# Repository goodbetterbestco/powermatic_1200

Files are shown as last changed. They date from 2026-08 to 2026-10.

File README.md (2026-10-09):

# Powermatic 1200 Controls Retrofit

Rev P is the current contactor-based design for the Powermatic 1200. Retain the existing motor, OFF/LOW/HIGH drum switch and fixed FWD/REV/STOP button station. Operator controls use 24 VDC; motor-power switching is located in the panel enclosure.

## Active files

- [Rev P BOM](Powermatic_BOM_revP.csv) — current component list, grouped by unique part number.
- [Wire-size policy](WIRING_STANDARD.md) — conductor gauges, motor/controls conduit plan, component exceptions and documentation responsibilities.
- [KiCad project](kicad/powermatic_1200/powermatic_1200.kicad_pro)
- [Schematic](kicad/powermatic_1200/powermatic_1200.kicad_sch) — work in progress.
- [Open work](TODO.md)

The contactor references are KF (forward), KR (reverse), KL (low speed), KH (high-speed supply) and KS (high-speed shorting). The current design also includes the selected disconnect, fuses, supply-input breaker, motor overloads, coil suppression, coil-enable relay, white indicator and M12 E-stop connection. The BOM records selected parts; schematic completion and commissioning remain open.

## Review the BOM

Use the local [BOM review editor](https://github.com/goodbetterbestco/bom_review)
to edit the CSV in a browser:

Double-click **Open BOM Review.app** in Finder. It opens the first CSV whose
filename contains `bom` (case-insensitive, alphabetically sorted) beside the
launcher. The launcher can be copied into another project folder to review its
BOM. Repeated launches reuse the same reviewer server. It runs in the background;
the launcher opens a Terminal window only when none exists and leaves existing
Terminal sessions alone. Closing Terminal does not stop the reviewer.

Or launch from a terminal:

```sh
python3 ~/Projects/bom_review/review.py ~/Projects/_hardware/powermatic_1200/Powermatic_BOM_revP.csv
```

The editor uses TYPE, NAME, QUA, PACK, UNIT, COST, LINE, SUPPLIER and SPN.
LINE calculates QUA × COST; the header total includes all parts. Blank and summary
rows are omitted. Other cells remain editable text. **Overwrite** saves directly
to the original project CSV. **Save CSV** downloads a separate copy. Relaunch the
Finder app after updating the reviewer to use its latest server features.

## Generate a wiring review

The [wire-size policy](WIRING_STANDARD.md) defines conductor classes and exceptions.
`Open BOM Review.app` and `Open Wire Schedule Review.app` use the shared
`bom_review` editor. On launch they extract fresh saved KiCad data into the
existing BOM or wiring CSV. The browser's Refresh button repeats extraction.
Overwrite saves browser edits only to that live CSV; it never writes to KiCad.
There is one CSV per schedule and no automatically retained CSV history.

The BOM's SOURCE column distinguishes KiCad-linked rows from Local purchasing
items. SOURCE KEY, hidden in the grid, identifies linked parts across refreshes.
KICAD QTY is the modeled count; purchasing QUA and packaging remain CSV data.
Refresh retains all Local rows and the purchasing fields on linked rows. Initial
tagging preserves all existing BOM values. See [schedule extraction](tools/schedules/README.md).

Both wire-review Finder apps use the same live `Wire_schedule.csv`. Complete
saved PCB trace paths become physical wire rows; bends/arcs/vias do not create
extra wires. Refresh updates routes and footprint termination data and reports
unrouted or ambiguous connections. There are currently no saved traces, so a
fresh schedule contains zero routed wires. Old `Wire.Wxxx` fields are not used.

See [KiCad-owned wiring](tools/wiring/README.md) for the record editor, routing
rules and generated coverage report. To generate without opening a browser:

```sh
python3 tools/wiring/generate.py
```

## Shared parts library

Control-net names follow the shared `_parts` naming convention. See the
[project signal table](SIGNAL_NAMING.md) for operator connections, enable paths,
coil feeds and intermediate links.

Reusable assets are kept in the separate `_parts` repository:

- `symbols/Controls.kicad_sym` — control symbols.
- `datasheets/` — product documents and drawings, including the May 1968 Bulletin 365 catalog.
- `3dmodels/Controls/` — 21 vendor STEP files and three user rail/duct STEP files, in their original orientations.
- `reviews/Controls_Panel_Models_2026-09-25/` — source mapping and verified file hashes.

Controls layout footprints have not been created. Model orientation, mounting datums and terminal positions still require review before footprint use. External L15-20 plug, drum-switch and button-station modeling is deferred. The fuse model is excluded; its holder and cover models are available.

Component placement will determine the enclosure size. The 350 mm DIN rail is the current working model; duct cut lengths and rail count remain to be determined.

## Archived working material

The mechanical collection, generated reports, previous BOM snapshot and earlier project notes are preserved in [archive commit 8ceac95](https://github.com/goodbetterbestco/powermatic_1200/tree/8ceac956c50b004d06b5bfea7e3169a44bf2d5c7). They were removed from the active tree after the archive was pushed and the shared-library asset copies were verified. Older Rev M design files remain in earlier Git history.

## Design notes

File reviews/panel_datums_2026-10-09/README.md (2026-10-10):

# Panel datums and integer wiring-target coordinates

Owner-authorized saved/paused checkpoint, 2026-10-09. Updated J2/J4/J5 glands,
SW1 disconnect, H1/H2 indicators and J1 M12 panel socket. Eight shared library
files include the underlying BNSPDX-23-W gland and its installed mains-plug proxy.

The glands use Y=0 at the outer wall and X=0 at the gland axis. SW1 uses X=0 at
the outer wall and Y=0 at the shaft axis. The lamps move the datum from the old
X=-16.82571 mm bezel underside to X=0. The M12 socket moves its modeled
sealing-ring rear tangent from old X=3 mm to X=0. This is the nominal modeled
seal plane; the STEP represents the uncompressed seal, not installed gasket
compression. The local TE drawing distinguishes the front shoulder, seal and
rear locking nut. The local Schneider drawing places the panel at the bezel
underside, 11 mm behind the operating face.

All 54 library pad centers, including the 46 targets in the seven installed
instances, are nearest-integer X/Y after the datum change; the largest rounding
adjustment on one axis is 0.45 mm. Native KiCad pad coordinates were checked
at an integral origin and at 0/90/180/270 degrees. These are panel-layout wiring
targets; rounding does not alter hardware outlines or manufacture dimensions.

Placed origins compensate the new local datums so the physical X/Y location,
orientation, model X/Y, drawing details and instance text remain fixed. Pad
numbers, nets, sizes, drills and UUIDs are retained. All 89 other instances and
all board text outside the seven edited footprint blocks remain byte-identical.
The current board has 277 pads and zero track segments, retained by the update.

H2 model Z was 0 mm while H1 model Z was 60.05 mm. H2 now uses 60.05 mm as well;
the lamp source's operating axis is 14.95 mm above its transformed model origin,
so both axes are 75 mm above KiCad's component plane, matching the SW1/J1
mounting-axis height. The two lamp library defaults also use 60.05 mm. H1's
placed height and all device wall positions remain fixed.

The five relevant schematic instances already select the same updated library
IDs. J4/J5 are PCB-only mechanical glands. The schematic is retained verbatim;
no symbol-body, wiring or footprint-ID migration is needed for this in-place
library update. Native netlist and ERC comparison checks the saved consuming
schematic. Baseline ERC: zero errors, one H1 library-symbol-mismatch warning.
The baseline DRC CLI aborted with exit 134 before producing a report.

`manifest.json` records exact origins, source/candidate hashes and every rounded
pad. `prepare.py` records the transformation. `layout.svg`/`layout.png` are
native exported isolated-footprint visual evidence: review-only crosses mark
origins; they are not installed device geometry. Appearance was inspected from
this export; no live symbol/editor inspection is claimed.

Applicable shared rules: FP-CTRL-001/005/009/010/011 retain true physical geometry,
full F.Fab detail, existing layer ownership and omitted courtyards. The owner's
explicit closest-integer pad instruction supersedes exact fan-out spacing in
FP-CTRL-002/003 for these wiring targets. FP-CTRL-006/007/008 preserve the existing
reference-only labels and their placed appearance. No electrical symbol geometry
was changed, and this is not a claim of full library-review completion.

Final saved-project checks: native library/board load and serialization/reload pass; all 63 net memberships are unchanged; ERC has zero errors and the unchanged one H1 library warning. Final DRC also aborts with exit 134 and produces no report. No DRC pass is claimed. `before.zip` in the consuming project review restores both project and library source checkpoint files.

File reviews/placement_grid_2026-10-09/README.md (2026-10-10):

# Integer panel placement and 462 mm backplate

Owner-authorized layout update, 2026-10-09. This PCB is an industrial-controls
alignment and routing view. Whole-millimetre datums take priority for ease of use.
The policy is recorded in the project's WIRING_STANDARD.md.

The backplate outline is 462 x 462 mm, from (0,0) to (462,462). Its existing
notches and mounting holes retain their local shapes, radii and distances from
the nearest edges. Upper corner groups move upward by 0.482 mm; right corner
groups move right by 0.482 mm. Long spans grow accordingly. The native outline
remains closed.

The enclosure remains 508 x 508 mm. Controls:EN4SD20208GY_Open_Front_Grid1mm
centers it on the 462 mm backplate with a 23 mm border. It retains the original
backplate lower-left footprint origin, placed at PCB (0,462). Enclosure corner
datums are (-23,-23), (485,-23), (485,485), (-23,485). The original library
footprint remains available as the nominal 461.518 mm backplate reference.

The new variant translates enclosure graphics by (+0.241,-0.241) mm and the
model by (+0.241,+0.241,0) mm, accounting for KiCad's opposite model/PCB Y axes.
The source STEP is unchanged and unscaled. Native CAD inspection found nine
solids, including the 508 mm housing, hardware and brackets; the backplate view
comes from the KiCad board. The mapped housing bounds agree with the 2D datums.

Wall-device positions:

| Reference | X mm | Y mm |
|---|---:|---:|
| H1 | -23 | 52 |
| SW1 | -23 | 130 |
| H2 | -23 | 207 |
| J1 | -23 | 308 |
| J2 | 57 | 485 |
| J4 | 385 | 485 |
| J5 | 435 | 485 |

All seven origins and all 46 placed wiring targets are now integer global X/Y.
The pad offsets, numbers, nets, dimensions and UUIDs from the previous datum
update are retained. H1/H2 retain their matching 60.05 mm model Z offsets.
The remaining 88 footprints, including fuse-insert/cover mating assemblies,
retain their saved origins and geometry. There are 96 footprints, 277 pads and
zero track segments before and after. Schematic and project settings are retained.

Native footprint/board load, board serialization/reload, whole-mm origin/pad
checks, backplate outline continuity and hole-radius checks pass. The focused
native SVG/PNG shows the frame and the seven wall devices; its extra viewport
outline is review-only. Appearance was inspected from that export.

Applicable checklist: FP-CTRL-001 preserves the hardware model geometry while
adapting the authorized routing view; FP-CTRL-009 retains layer ownership;
FP-CTRL-011 retains the enclosure/device physical projections without adding
courtyards. No electrical symbol body changes or live Symbol Editor review are
claimed. This is not a PCB fabrication footprint/layout review.

`manifest.json` records exact placement and model bounds, `prepare.py` records
the transforms, and `before.zip` restores the pre-update project files.

Final saved-project ERC reports zero violations. The DRC CLI aborts with exit 134 before writing a report, as in prior checks; no DRC pass is claimed. Final native checks and source-preservation results are recorded in validation.json.

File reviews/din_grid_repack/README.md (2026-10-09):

# DIN layout and pin-coordinate audit

The final layout uses 12 shared `_Grid1mm` variants on 71 eligible DIN footprint instances.
All 205 pin pads in those instances and both mounting faces are on exact integer coordinates.
The two rows are packed as assemblies on Y=130 mm and Y=308 mm; their grid-body envelopes
fit the existing 400 mm rails without overlap between independent assemblies.

The original nominal footprints, STEP models and F.Fab detail are retained as hardware
references. The grid variants implement the owner-requested routing representation.
Pin coordinates use upward ceiling rounding. Halfway mounting walls use the outward
integer. Fuse inserts/covers retain mating offsets, and non-DIN components were unchanged.

The final saved PCB contains 96 footprints and 277 numbered pin pads. 86 footprint origins have integer X and Y; ten remain fractional: six fuse/cover mating datums and four wall connectors.
The coordinate workbook includes every pin pad and every footprint origin. The 36
padless footprints are listed on the Origins worksheet; no pin coordinates were invented.

## Grid classification

Coordinates are absolute KiCad board millimetres: X increases right, Y increases down.
The saved grid origin is (0,462) mm. Both axes must match exactly; no numerical tolerance
is applied. Metric candidates are 5, 2.5, 2, 1, 0.5, 0.25, 0.2, 0.125, 0.1, 0.0625,
0.05, 0.025 and 0.01 mm. Inch candidates are 100, 50, 25, 10, 5 and 1 mil.
`None of tested grids` means no match in this finite set; a finer or shifted lattice
may still describe the point. Local footprint coordinates and local grid matches are
also included, so nominal terminal geometry can be distinguished from placement offsets.

## Files

- [Final layout and validation](grid1mm/README.md)
- [Final exported layout](grid1mm/layout.png)
- [Sortable coordinate workbook](../../outputs/01a11f24-8bcc-77e0-af58-1f3d5466a457/pin_coordinates.xlsx)
- [Complete coordinate JSON](coordinates.json)
- [Original source recovery snapshot](before_board.zip)
- [Before-grid PCB and schematic snapshot](grid1mm/before_grid.zip)

## Final grid counts

| Classification | Pins |
|---|---:|
| Metric | 205 |
| None of tested grids | 72 |

## Remaining fractional footprint origins

| Reference | Part | X (mm) | Y (mm) | Reason |
|---|---|---:|---:|---|
| F1 | FRN-R-10 | 84.484112 | 130.000000 | Assembly mating datum |
| F2 | FRN-R-10 | 109.484112 | 130.000000 | Assembly mating datum |
| F3 | FRN-R-10 | 134.484112 | 130.000000 | Assembly mating datum |
| J1 | T4171310004-001 | -25.000000 | 307.500000 | Outside DIN repacking scope |
| J2 | 3PH-4W-PLUG | 57.000000 | 485.241000 | Outside DIN repacking scope |
| J4 | BSPDX-23-W | 385.000000 | 485.241000 | Outside DIN repacking scope |
| J5 | BSPBX-22-W | 435.000000 | 485.241000 | Outside DIN repacking scope |
| REF** | CVR-RH-25030 | 84.500000 | 130.000000 | Assembly mating datum |
| REF** | CVR-RH-25030 | 109.500000 | 130.000000 | Assembly mating datum |
| REF** | CVR-RH-25030 | 134.500000 | 130.000000 | Assembly mating datum |

Source SHA-256: `fbe823d4e8d51115c49e3e389eada75a6284db6dfc230625cb2b023f1e0f2385`.

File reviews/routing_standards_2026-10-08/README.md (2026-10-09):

# Routing standards — 2026-10-08

The saved project now has six AWG width profiles and functional netclasses for
incoming mains, panel power, motor power, control, direction, speed and PE.
A separate DEVICE_INTERNAL class marks retained straps and direct-mounted
connections without assigning a conductor gauge. See
[WIRING_STANDARD.md](../../WIRING_STANDARD.md#kicad-route-widths-and-netclasses)
for the policy and routing instructions.

KiCad 10.0.7 natively resolved all 53 named nets: 43 have an AWG default and
10 fixed connections retain the Default drawing width. Thirteen nets have
different gauges on different physical wires; select the appropriate AWG preset
for those individual conductors. The six available presets are 0.643, 1.024,
1.290, 1.628, 2.052 and 2.588 mm.

The PCB Editor preference is 90 degree rounded, with free-angle mode disabled.
The project local settings disable width pickup from existing tracks and enable
netclass grouping in Net Inspector. These are saved preferences for the next
editor launch. The corner mode remains selectable through KiCad shortcuts.

Validation: native project loading and netclass resolution passed. Both the
96-footprint PCB and the schematic remain byte-for-byte identical to the
user-saved baseline. The 18 existing 0.2 mm track segments were preserved.
The project diff is limited to netclasses, assignment patterns and width presets;
existing user changes were retained.

The full assignment table, mixed-gauge declarations, native effective widths,
source hashes and preference-backup path are in [assignments.json](assignments.json).

| Net | Functional group | Default AWG | Default width (mm) | Declared AWGs |
|---|---|---:|---:|---|
| `+24V` | `CONTROL` | 18 | 1.024 | 18, 22 |
| `+24V_EN` | `CONTROL` | 18 | 1.024 | 18 |
| `/CONTROL_ESTOP_CONTACT_LINK` | `CONTROL` | 22 | 0.643 | 22 |
| `/CONTROL_K3_CONTACT_LINK` | `CONTROL` | 18 | 1.024 | 18 |
| `/DIRECTION_FWD_COIL` | `DIRECTION` | 18 | 1.024 | 18 |
| `/DIRECTION_REV_COIL` | `DIRECTION` | 18 | 1.024 | 18 |
| `/HS_SHORT` | `PANEL_POWER` | 14 | 1.628 | 14 |
| `/L1_FUSED` | `PANEL_POWER` | 14 | 1.628 | 14 |
| `/L1_HIGH` | `MOTOR_POWER` | — | — | fixed |
| `/L1_LOW` | `MOTOR_POWER` | — | — | fixed |
| `/L1_PSU` | `PANEL_POWER` | 14 | 1.628 | 14 |
| `/L2_FUSED` | `PANEL_POWER` | 14 | 1.628 | 14 |
| `/L2_HIGH` | `MOTOR_POWER` | — | — | fixed |
| `/L2_LOW` | `MOTOR_POWER` | — | — | fixed |
| `/L2_PSU` | `PANEL_POWER` | 14 | 1.628 | 14 |
| `/L3_FUSED` | `PANEL_POWER` | 14 | 1.628 | 14 |
| `/L3_HIGH` | `MOTOR_POWER` | — | — | fixed |
| `/L3_LOW` | `MOTOR_POWER` | — | — | fixed |
| `/SPEED_HIGH_SHORTING_COIL` | `SPEED` | 18 | 1.024 | 18 |
| `/SPEED_LOW_COIL` | `SPEED` | 18 | 1.024 | 18 |
| `0V` | `CONTROL` | 18 | 1.024 | 18 |
| `CONTROL_ESTOP_DISABLED_FB` | `CONTROL` | 18 | 1.024 | 18 |
| `CONTROL_ESTOP_ENABLE` | `CONTROL` | 18 | 1.024 | 18, 22 |
| `CONTROL_LOW_OVERLOAD_ENABLE` | `CONTROL` | 18 | 1.024 | 18 |
| `CONTROL_OVERLOAD_ENABLE` | `CONTROL` | 18 | 1.024 | 16, 18 |
| `CONTROL_RUN_ENABLE` | `CONTROL` | 18 | 1.024 | 16, 18 |
| `DIRECTION_ENABLE` | `DIRECTION` | 18 | 1.024 | 16, 18 |
| `DIRECTION_FWD_CMD` | `DIRECTION` | 18 | 1.024 | 16, 18 |
| `DIRECTION_REV_CMD` | `DIRECTION` | 18 | 1.024 | 16, 18 |
| `L1_DIR` | `PANEL_POWER` | 14 | 1.628 | 14 |
| `L1_IN` | `INCOMING_MAINS` | 12 | 2.052 | 12, 14 |
| `L1_SW` | `PANEL_POWER` | 14 | 1.628 | 14 |
| `L2_DIR` | `PANEL_POWER` | 14 | 1.628 | 14 |
| `L2_IN` | `INCOMING_MAINS` | 12 | 2.052 | 12, 14 |
| `L2_SW` | `PANEL_POWER` | 14 | 1.628 | 14 |
| `L3_DIR` | `PANEL_POWER` | 14 | 1.628 | 14 |
| `L3_IN` | `INCOMING_MAINS` | 12 | 2.052 | 12, 14 |
| `L3_SW` | `PANEL_POWER` | 14 | 1.628 | 14 |
| `M1_T1` | `MOTOR_POWER` | 14 | 1.628 | 14 |
| `M1_T2` | `MOTOR_POWER` | 14 | 1.628 | 14 |
| `M1_T3` | `MOTOR_POWER` | 14 | 1.628 | 14 |
| `M1_T4` | `MOTOR_POWER` | 14 | 1.628 | 14 |
| `M1_T5` | `MOTOR_POWER` | 14 | 1.628 | 14 |
| `M1_T6` | `MOTOR_POWER` | 14 | 1.628 | 14 |
| `Net-(S3-HI3_B)` | `SPEED` | — | — | fixed |
| `Net-(S3-HI5_T)` | `SPEED` | — | — | fixed |
| `Net-(S3-HI6_T)` | `SPEED` | — | — | fixed |
| `Net-(S3-HI8_B)` | `SPEED` | — | — | fixed |
| `PE` | `PE` | 14 | 1.628 | 12, 14 |
| `SPEED_HIGH_CMD` | `SPEED` | 18 | 1.024 | 16, 18 |
| `SPEED_HIGH_COIL` | `SPEED` | 18 | 1.024 | 18 |
| `SPEED_LOW_CMD` | `SPEED` | 18 | 1.024 | 16, 18 |
| `SPEED_LOW_K6_NC_LINK` | `SPEED` | 18 | 1.024 | 18 |

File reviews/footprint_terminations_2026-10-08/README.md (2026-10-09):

# Footprint-owned terminations

The owner requires TERM 1 and TERM 2 to belong to their endpoint parts. The
saved PCB now holds 305 hidden F.Fab `Termination.<terminal>` fields on 67
footprints. Edit these selections in Footprint Properties. They are project
instance data, so preserve them when updating footprints from their libraries.
Reports are derived outputs.

The migration moves all 182 existing symbol termination fields into their
corresponding footprints and removes the symbol copies. It also removes
`term1`/`term2` from the three surviving schematic wire records. The generator
reads TERM 1 from the source footprint and TERM 2 from the destination footprint.
Missing footprint fields stop export instead of using a wire-record fallback.
The record editor no longer accepts termination-copy arguments.

All 33 feedthrough/ground blocks' 66 wire clamps now describe the part capability:
`Ferrule or twin ferrule as required`. One conductor uses a ferrule; two in one
clamp use a twin ferrule. The owner clarified that blocks and unused jumpers
are available graphics until needed during routing. Part fields therefore carry
no wire-gauge or barrel-length assignment, and unallocated clamps are not
reported as missing termination choices. Actual conductor gauges remain in wire
records/sizing declarations. Ferrule size, length and single/twin form are chosen
when routing assigns conductors. Every block records `Wire.TerminationPolicy`;
grounding-block PE rail feet retain their conductive-contact classification.
`ferrule_policy.json` records the initial family requirement and
`block_capabilities.json` records the owner's allocation clarification and
geometry-preservation check. Other parts' existing barrel-length and
ring-dimension TBDs are retained.

Gland route markers are classified as cable pass-throughs without electrical
terminations. Mechanical interlock markers and grounding-terminal rail contacts
are also classified explicitly. Legacy enclosure, door and backplate stud
descriptions live on the enclosure footprint; rail lug descriptions live on the
two rail footprints. Those legacy bond selections remain pending reconciliation
with the newer bonding plan and do not establish additional wire connections.

At the owner's request M1, J2, S1 and J6 now have metadata-only footprints.
Their terminal inventory is stored in `Wire.TerminalPins`, with one termination
field per terminal. They have no pads, artwork or models, are marked board-only,
allow missing courtyards, and are excluded from BOM and position exports. Their
hidden fields on F.Fab do not change the panel drawing. Their schematic symbols
and electrical connections are retained.

H1 and H2 still have older symbol UUIDs in the board paths. Before associating
their termination fields, the migration verified unique references, matching
MPNs, complete matching terminal inventories and identical native net names.
It preserves the existing paths, placements and models. Both receive the
existing blue 18 AWG indicator ferrule selection.

Validation performed:

- Native KiCad PCB loading: 97 footprints, 305 hidden termination fields.
- Four metadata-only owners: zero pads, graphic items or models and the intended
  board-only/BOM/position exclusion attributes.
- Structured comparison: every original footprint's geometry, placement, pads,
  nets, models, UUIDs and non-termination fields unchanged. All other PCB objects
  unchanged. Schematic changes restricted to removal of termination copies.
- Native schematic netlist comparison: all 186 pin-to-net assignments identical.
- Migration repeated on its result: byte-for-byte idempotent.
- 33 wiring tests passed, including conflicting owner selections, migration,
  external owners, footprint edits flowing into schedule output and missing
  fields rejecting stale wire-record fallbacks.
- Source hashes checked before installing both saved files after the owner's
  saved/editing-paused confirmation. Whitespace check passed.

`validation.json` records hashes and preservation checks. `provenance.json`
records the origin of every migrated selection. These are evidence, not runtime
data sources. Run `python3 tools/wiring/terminations.py` to review the saved PCB.

The rest of the physical wire-record migration remains unchanged. Complete
schedule generation still fails on deleted schematic endpoint UUIDs. No wire
allocation, routing, cut-length redesign, DRC severity changes or library edits
were included in this task.

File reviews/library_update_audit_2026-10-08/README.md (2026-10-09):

# Schematic library-update audit — 2026-10-08

The saved schematic has ten library-symbol-mismatch warnings and no ERC errors.
All ten instance caches were compared with the current Controls definitions selected
by their non-LCSC catalog records. The pin sets, names, electrical types, full pin
definitions (including coordinates, lengths and text styles), body geometry and
root electrical/placement attributes agree.

| References | Part | Pins per symbol | Electrical/drawing differences |
|---|---|---:|---|
| SP1, SP2, SP4, SP5, SP6 | HMX1-SSVRC-DC | 2 | None |
| FH1 | RM25030-3SR | 6 | None |
| SW1 | 222102 | 6 | None |
| K3 | HC3096N-52-900-24 | 10 | None |
| Q1 | FAZ-D4-2-NA-L | 4 | None |
| PS1 | NDR-240-24 | 7 | None |

The cached copies contain database-added Part ID, Supplier, Supplier PN, inventory
and footprint-filter properties not present in the underlying Controls templates.
K3 also has catalog Package=DIN-RAIL, while its underlying template Package is empty.
These differences do not alter the connection interface. This identifies the source
of the underlying-definition differences, but does not claim every metadata detail
of KiCad's runtime database-generated symbol has been reproduced.

## Update settings

Update only these ten selected instances. Uncheck all Update/Reset Fields selections
and disable Remove fields if not in library, Reset fields if empty in library,
Update/reset field text, visibilities, sizes/styles and positions. Leave Reset alternate
pin to default off. Preserve Wire.*, Termination.*, Mounting, exact MPN, footprint
and the drafted reference/value/Part Name positions.

Run ERC and compare the native netlist after the actual editor update. A temporary
metadata-only cache comparison copy preserved all net memberships, pin functions
and electrical types, but still produced ten warnings. It is not a native editor
update and is not a candidate to install; clearance of the warnings remains to be
verified after the actual library update.

No schematic, PCB or shared-library source files were modified by this audit.
The PCB DRC CLI aborted with exit 134 before producing a report. The owner's
exported PCB-editor DRC report is needed to classify the approximately 300 findings.

This is an electrical-equivalence and structured drawing comparison. No fresh
visual or live Symbol Editor review was performed in this audit; SYM-VIS-001
remains outside this check and no full library-review completion is claimed.

[KiCad update-symbol documentation](https://docs.kicad.org/10.0/en/eeschema/eeschema.html#updating-and-exchanging-symbols)

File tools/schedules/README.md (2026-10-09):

# Live schedule extraction

`kicad_schedules.json` connects the shared `bom_review` Finder launcher and Refresh
server to this project's `extract.py`. Each mode has exactly one live CSV:
`Powermatic_BOM_revP.csv` and `Wire_schedule.csv`. Successful extraction overwrites
that file. Failure preserves it. No CSV versions or backup files are retained.
Make any desired copies elsewhere yourself.

The browser/editor, source-tag preservation, generic BOM row merge and refresh
transaction live in `/Users/evanthayer/Projects/bom_review`. This adapter reads
the saved schematic and PCB and applies Powermatic's component/wire rules.

## BOM ownership

- SOURCE=KiCad: linked to a stable SOURCE KEY and refreshed from modeled parts.
- SOURCE=Local: purchasing-only data remains in this CSV and survives refresh.
- KICAD QTY: modeled piece count, independent of purchasing QUA and packaging.

Initial tagging only adds these columns; it preserves every existing nine-column
cell. Matches use unique saved MPN/supplier identifiers, whole identifier tokens
in vendor-prefixed SKUs or unique part names. Ambiguous rows stay Local.

Refresh updates a linked part's name where KiCad provides one and its modeled
count. Local purchasing quantity, price, packaging, supplier and supplier SKU
are retained. Explicit `BOM.PACK`, `BOM.UNIT`, or `BOM.COST` KiCad fields can
supply those purchasing fields when present. Newly specified native parts are
added with purchasing quantity left for the user. Deleted linked parts are
removed; Local entries are kept.

This is a panel BOM. Existing purchasing rows can link to mechanical Controls
models even when those models are excluded from a conventional PCB BOM. Their
modeled quantities include available graphics and are informational until
physical allocation. Such excluded models do not create new purchasing rows.
Metadata-only footprints are not counted again; schematic units and placed
footprints representing the same component are counted once. Assemblies without
an actual part identifier are not automatically added as new purchasing SKUs.

## Wiring ownership

The saved PCB traces are the physical wire source. A continuous pad-to-pad
path produces one wire row. Connected segments, bends, arcs and via layer changes
remain within that wire. A terminal met along the path splits it into separate
wires. Branches away from a terminal/splice footprint are rejected as ambiguous;
unfinished paths are omitted and reported. Cable-gland IN/OUT routing markers
continue the same wire, using their saved jumper groups, rather than becoming
extra wire ends. Unused block graphics produce no wires.

Endpoint nets are checked against the saved schematic. Board-only unassigned
clamps acquire the circuit from their actual traced connections for export;
different nets on internally common clamps are rejected. The exporter does not
write back to KiCad or assign pad nets in the source file.

AWG comes from footprint `Wire.AWG.<pin>` overrides, schematic `Wire.Sizes`, or an
existing gauge-bearing termination selection. Missing/conflicting sizes stay
blank with a warning; copper trace width is not interpreted as a wire gauge.
Terminations come from footprints. Generic block fields resolve to single or
twin ferrules based on the number of completed routed wires sharing that clamp.

LENGTH is a cut estimate: native route length plus 100 mm, rounded upward to
10 mm. Native arcs use curved length.
Vias are drawing-layer transitions and add no physical via/PCB-thickness length.

Stale sizing metadata produces warnings and cannot supply an outdated gauge.
Conflicting nets on internally common block clamps are reported without hiding
the recorded routes. These wires have `net-conflict` review state in the
extraction report, and the overall routing review remains incomplete.

Old schematic `Wire.Wxxx` records are no longer a route source and do not block
trace export. There are currently no saved traces, so fresh wiring extraction
produces the eight-column header with zero routed wires and reports incomplete
electrical coverage. Only a saved completed trace path adds a wire; drawing in
an unsaved editor does not change extraction.

## Data direction

Saved KiCad data flows into the schedules. CSV-owned purchasing entries/fields
stay local. Browser Overwrite saves only the current CSV, including source tags.
There is no path from a browser edit back into the schematic, PCB or libraries.

Tests cover source changes, package quantity preservation, Local row retention,
removed linked parts, duplicate/missing keys, ambiguous matching, CSV tag round
trips, refresh failures and concurrent saves.

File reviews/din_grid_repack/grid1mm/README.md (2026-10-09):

# Grid-aligned DIN layout

Installed 12 shared `_Grid1mm` elevation variants on 71 placed footprint instances.
All 205 pin pads in those instances lie on exact integer X/Y coordinates.
Their left and right mounting faces are also integer X. The 77 DIN-associated
instances were restacked as assemblies on the existing 130 mm and 308 mm rail
centre lines, keeping both 400 mm rails. Fuse inserts/covers keep their mating
offsets; their noninteger origins exclude them from the grid-variant operation.

The original footprints and STEP model parameters are preserved. F.Fab remains
the nominal hardware reference; the visible grid view and wire-target markers
are a routing representation. This review verifies 2D grid-envelope packing,
not a change in the manufactured hardware dimensions.

Native checks retain all 96 footprint instances, 277 pin pads, 18 track segments
and the four completed routed endpoint pairs. Schematic footprint overrides
were updated in 16 placed symbols; all 63 nets and 186 pin/net memberships are unchanged.

The exported [layout](layout.png) was visually inspected. Per-instance positions,
route adjustments and identity checks are in [packing.json](packing.json).
The [variant manifest](variants.json) records source hashes and pin rounding.
The preceding saved PCB and schematic are recoverable from [before_grid.zip](before_grid.zip).

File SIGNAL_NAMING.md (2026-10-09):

# Powermatic control signal names

The shared [signal naming standard](../../_parts/SIGNAL_NAMING_STANDARD.md)
governs this project. Use `[FUNCTION]_[DETAIL]_[ROLE]` in uppercase, with the
detail omitted when unnecessary. The active functions are `CONTROL`,
`DIRECTION`, and `SPEED`. Control signals use `CMD`, `ENABLE`, `FB`, `COIL`,
or `LINK` as their role; power rails and motor power conductors retain their
electrical names.

The saved schematic owns net names and connectivity. PCB pad nets, embedded
`Wire.Sizes` declarations, physical wire records and generated outputs must
use that same native name. A leading `/` in KiCad exports denotes sheet scope
and is not part of the functional naming convention. Reusable symbol pin names
and physical terminal numbers remain manufacturer/contact functions.

## Operator connections

| Signal | S2/S3 terminal | Energized meaning |
|---|---|---|
| `CONTROL_OVERLOAD_ENABLE` | S2.5T; retained links to 1T and 3T | Feed has passed the upstream control enable and both overload NC contacts. |
| `CONTROL_RUN_ENABLE` | S2.6T; S3.1B with retained link to 2B | The overload-qualified feed has also passed STOP's NC contact. |
| `DIRECTION_ENABLE` | S2.2B with required link to 4B | Either speed contactor K4 or K6 has closed its auxiliary NO contact, supplying the direction start/holding circuits. |
| `DIRECTION_FWD_CMD` | S2.1B | Forward command path is energized by the button or K1's holding contact. |
| `DIRECTION_REV_CMD` | S2.3B | Reverse command path is energized by the button or K2's holding contact. |
| `SPEED_LOW_CMD` | S3.1T with retained link to 3T | LOW selector command path is energized. |
| `SPEED_HIGH_CMD` | S3.2T | HIGH selector command path is energized. |

S2 retains five external conductors and S3 retains three. This naming update
does not change any connection or establish installation of an unconfirmed link.
The S2 2B-to-4B link remains required and physically unconfirmed.

An energized command net does not prove a button remains pressed or a motor is
moving. `CONTROL_RUN_ENABLE` is a positive permission path, not an active-high
STOP request. Loss of a cumulative enable may result from any upstream open
contact or missing feed; it does not uniquely diagnose the last device.

## Other named control nets

| Signal | Function |
|---|---|
| `CONTROL_ESTOP_ENABLE` | Feed through the E-stop contact chain to K3's coil. |
| `CONTROL_ESTOP_DISABLED_FB` | K3 NC31-32 supplies the red H2 lamp when the E-stop enable relay is released and 24 V power is present. This also indicates an unplugged/broken E-stop loop or a failure to energize K3; it does not uniquely identify the physical button position. |
| `CONTROL_LOW_OVERLOAD_ENABLE` | Intermediate feed after OL4's NC contact and before OL6's NC contact. |
| `DIRECTION_FWD_COIL` | K1 coil feed after the reverse contactor's NC interlock. |
| `DIRECTION_REV_COIL` | K2 coil feed after the forward contactor's NC interlock. |
| `SPEED_LOW_COIL` | K4 coil feed after the high-speed interlocks. |
| `SPEED_HIGH_SHORTING_COIL` | K5 shorting-contactor coil feed after K4's NC interlock. |
| `SPEED_HIGH_COIL` | K6 coil feed after K5's NO sequencing contact. |
| `SPEED_LOW_K6_NC_LINK` | Intermediate low-speed command path between K6's and K5's NC interlock contacts. |
| `CONTROL_ESTOP_CONTACT_LINK` | Intermediate connection between the two E-stop NC contacts. |
| `CONTROL_K3_CONTACT_LINK` | Intermediate connection between K3's series NO contacts. |

`FB` is reserved for an actual feedback contact or sensor. No feedback signal
introduced here indicates shaft motion. A contactor auxiliary contact confirms its defined
contact state, not measured shaft speed or direction. `+24V`, `+24V_EN`, `0V`,
`PE`, phase-stage names and motor terminal names remain power-net identifiers.

## Verification of the naming update

The 2026-10-08 update preserves all net terminal memberships, symbol pin functions
and electrical types. PCB changes are name substitutions only. One schematic
coil label rotates at its original connection point to avoid overlapping a
neighboring symbol. Wires, UUIDs, terminal numbers, component positions and models
are unchanged.
Validate the final native netlist and embedded sizing declarations together.
Review exported operator/control artwork for label readability.

| Shared rule | Result | Evidence |
|---|---|---|
| `SCH-NAME-001` | Pass | All 17 explicitly named control nets use the shared roles. No remaining old-name usages were found in either repository's current searchable files. |
| `SCH-NAME-002` | Pass | Operator/cumulative meanings are recorded above; the native exports were inspected, and the long K5 coil label was rotated without moving its connection point. |
| `SCH-NAME-003` | Pass | Before/after native netlists retain all 64 net groups with identical terminal memberships, pin functions and electrical types. PCB sources retain every non-name byte; schematic sources differ only in names and one label rotation. |

Native PCB loading confirms 90 footprints and 279 pads. The sizing validator
classifies all 172 connected terminals, including eight external S2/S3 wires.
All 27 existing wiring tests pass. Final ERC has zero errors and the same ten
library-symbol-mismatch warnings as the baseline; its violation records are
identical. These checks validate the rename, not fabrication or electrical release.

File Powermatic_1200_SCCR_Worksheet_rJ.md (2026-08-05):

# Powermatic 1200 Retrofit - SCCR Worksheet

**Revision:** J  
**Date:** 2026-08-05  
**Circuit:** nominal 208/240 V, 3-phase VFD input power circuit  
**Status:** **SELECTED POWER-CIRCUIT COMPONENT CHECK PASSED - final panel sign-off requires source verification**

## 1. Design target and source assumption

- Working panel target: **10 kA RMS symmetrical at 240 V maximum**.
- Shop feeder: Siemens three-pole Type QP branch breaker marked **10,000 A RMS symmetrical at 240 V**.
- The breaker's 10 kA interrupting rating is not a calculation or measurement of available fault current.
  Treat `available fault current <= 10 kA` as a provisional design assumption until confirmed from the
  serving transformer and conductor impedance or by a qualified field calculation.
- The finished panel SCCR must be at least the available fault current at the machine connection point.

## 2. Power-circuit path

`shop feeder -> ABB OT30F3 -> LFT300603C / 3 x TJN35 -> Contactor A -> GS23-22P0 VFD`

| Component | Selected device | Published/working SCCR basis | Worksheet result |
|---|---|---|---|
| Branch fuses | 3 x Mersen `TJN35`, Class T, 35 A | Class T current-limiting branch protection; interrupting rating to be retained with the fuse data sheet | Not the limiting component |
| Fuse block | Littelfuse `LFT300603C`, 300 V, 60 A, 3-pole Class T | Listed Class T block; fit one `LFT30060FBC` cover per pole | Not presently identified as limiting |
| Disconnect | ABB `OT30F3`, 30 A, 3-pole, UL 98 | ABB publishes **50 kA** with Class T fuses up to 60 A | Passes 10 kA target |
| Contactor A | Schneider `LC1D18BD`, 18 A AC-3 / 32 A AC-1, 24 VDC | Schneider high-fault table: **100 kA with fuse <=40 A**. Selected fuse is 35 A Class T. | **Passes 10 kA target** |
| VFD | AutomationDirect `GS23-22P0` | GS20 manual specifies 35 A fast-acting Class T `TJN35`; all GS20(X) drives are suitable for circuits up to 100 kA RMS symmetrical | **Passes 10 kA target** |
| Feeder breaker | Siemens Type QP, 3-pole | 10 kA interrupting rating at 240 V; this is not the panel SCCR and not proof of available fault current | Source assumption only |

## 3. Resolution and remaining release items

The former `LC1D09BD` was replaced by `LC1D18BD`. This clears the contactor/fuse mismatch: the selected
35 A Class T fuse is below Schneider's 40 A maximum for the contactor's 100 kA high-fault combination.

Before applying the final panel SCCR marking:

1. Retain the Schneider combination-table page in the panel file and record `LC1D18BD`, 35 A Class T,
   and 100 kA component/combination SCCR.
2. Retain the GS20 manual pages showing `GS23-22P0` with 35 A `TJN35` Class T protection and the
   100 kA short-circuit-withstand statement.
3. Confirm available fault current at the machine by qualified calculation. The branch breaker's 10 kA
   interrupting rating alone does not establish available fault current.
4. Complete the final sign-off fields below and mark the panel at the lowest supported circuit value.

The contactor and VFD no longer present unresolved procurement holds. Do not apply the final panel SCCR label
until the available-fault-current entry and final field sign-off are complete.

## 4. Final sign-off fields

- Available fault current at machine: __________ kA RMS symmetrical at __________ V
- Calculation/source and date: _________________________________________________
- Final Contactor A catalog number: ____________________________________________
- Final fuse catalog/rating: ___________________________________________________
- VFD manufacturer SCCR condition verified: **Yes - GS20(X) manual, 1st Edition Rev E, pp. A-2/A-4 and 2-21**
- Lowest component/combination SCCR: __________ kA
- Final panel SCCR marking: __________ kA RMS symmetrical at __________ V
- Reviewed by / date: __________________________________________________________

## 5. Manufacturer references

- Schneider Electric, *Motor Control Solutions for the North American Market*, TeSys Deca 3-pole
  contactor SCCR table: `LC1D09` maximum 25 A fuse; `LC1D18` maximum 40 A fuse.
  <https://productinfo.se.com/8536db0901_motorcontrolsolutions_db/8536db0901-db-motor-control-solutions/English/8536DB0901R0119%20Motor%20Control%20Solutions%20for%20th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>
- Schneider Electric, LC1D mirror contacts: base-device 21-22 N.C. is the mirror contact.
  <https://www.se.com/uk/en/faqs/FA142116/>
- ABB, `OT30F3` product data and disconnect-switch short-circuit tables.
  <https://empower.abb.com/ecatalog/ec/EN_NA/p/1SCA105068R1001>
- Littelfuse, `LFT300603C` Class T block product data.
  <https://www.littelfuse.com/products/fuses-overcurrent-protection/fuse-holders-fuse-blocks-accessories/fuse-blocks/industrial-fuse-blocks/lft/lft300603c>
- AutomationDirect, *DURApulse GS20 & GS20X Drive User Manual*, 1st Edition Rev E: fuse specification
  table (`GS23-22P0` -> 35 A `TJN35`) and 100 kA short-circuit-withstand statement.
  <https://cdn.automationdirect.com/static/manuals/gs20m/gs20m.pdf>

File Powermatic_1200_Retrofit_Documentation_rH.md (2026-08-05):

# Powermatic 1200 Drill Press — Controls Retrofit

**Machine:** 1967 Powermatic 1200, 3PH tapping/drilling drill press
**Owner / designer:** Evan Thayer — GoodBetterBestCo
**Document rev:** H · **Date:** 2026-07-19
**Design references:** NFPA 79 (Electrical Standard for Industrial Machinery), UL 508A (panel construction)

> **Rev H changes (operator model + logic hardening; prox PNP; pricing).**
> - **Latched bidirectional DRILL run (§3.2, §7).** Reverse now behaves exactly like forward: **one press of REV
>   latches a reverse run** (`C31`) that continues until STOP — symmetric with FWD's `C30`. **Stop-first, opposite-
>   as-stop:** while running one direction, a press of STOP *or* of the opposite button **stops** the run; it takes
>   a **second** press to start the other direction (no plug-reversal under power). The old momentary REV jog on
>   `X005` is removed from normal operation and folded into jog mode below.
> - **JOG MODE (§3.5, §7).** **Hold FWD ≥ 5 s** to enter jog (FWD only). In jog mode **FWD and REV become momentary
>   hold-to-run jogs at 30 Hz** (preset-LOW forced), gated safe/no-fault. **Exit** on a **short (< 5 s) STOP press**,
>   or **60 s idle**, or **any fault**, or **E-stop**. STOP always stops motion first; the < 5 s qualifier only adds
>   the mode-exit. Annunciated as **blinking green = JOG ARMED** (see indicators).
> - **TAP abort hardened (§7 RUNG 13).** A loss of run-permit — which includes an **E-stop / safety trip** (`X011`),
>   drum-OFF, or STOP — now forces the TAP state machine to **IDLE**. Previously `C2`/`C3` survived an E-stop, so a
>   safety reset could **resume a tap with no fresh FWD press**; that auto-restart path is closed. DRILL already
>   self-cleared via `¬C20`; TAP now matches.
> - **DB-resistor over-temp is self-clearing + distinctly annunciated (§4/§7).** Over-temp now drives a dedicated
>   **`C11` (THERMAL)** bit that follows `X012` with a short cool-down delay — it inhibits run and **self-clears**
>   when the resistor cools (no manual reset, and no more fighting the fault-reset rung). Shown as **blinking red**,
>   distinct from a solid-red hard fault, so the operator reads "let it cool" vs "investigate."
> - **Indicators (§4/§7 RUNG 28/29).** Four states on the two machine-front lamps, exactly one active: **green solid**
>   = all-good; **green blink** = jog armed; **red blink** = DB over-temp (self-clearing); **red solid** = safety
>   trip or latched hard fault (top priority). White bus lamp unchanged.
> - **Feed-lever prox NPN → PNP (§4, §12).** Swapped to a **P&F NBN8-12GM50-E2-V1 (PNP-NO)** so it lands on the
>   **standard sinking input common** with every other +24-fed contact. The Rev G split-common (dedicated sourcing
>   group for the NPN unit) is deleted — `X010` stays put, logic sense and fail-safe behavior unchanged.
> - **STO wiring rationale recorded (§6).** STO1/STO2 are fed from the **single** safety output 23-24 by design;
>   **Contactor A (13-14) is the diverse, independent stop channel** and the CWBS12 mirror contact catches a weld
>   via EDM. Redundancy lives in the contactor path, not in STO's own two channels — documented, not changed.
> - **Selector detail (§4).** `X001`/`X002` come from the owner's **XB4BD21** with **both N.O. blocks installed**
>   (supersedes the "ZBE-101" placeholder).
> - **Pricing reconciled (BOM).** DB resistor $55 → **$156** and Contactor A ~$60 → **~$150** were materially low;
>   most other itemized parts verified in-range. See `..._BOM.md`.

> **Rev G changes (procurement + inventory pass; pilot scheme finalized).**
> - **Disconnect re-architected** to a **non-fused rotary switch + separate Class J fuse block** instead of an
>   integrated fusible unit: **Socomec SIRCO M Compact** (UL 98, 3-pole, 60 A, 100 kA SCCR — AD 22013006) feeding a
>   **Mersen US6J3** finger-safe Class J block (3× **JHL35**, Class J 35 A). Operated by an **external S00 rotary
>   handle (Socomec 14741111, NEMA 3R/12)** mounted on a **fixed enclosure wall — not the door** — with **no
>   through-door coupling rod**. Padlockable in OFF; sole disconnecting means.
> - **Contactor A fixed as a WEG CWBS12-33-30C03** IEC **safety contactor** (3-pole, 12 A, 24 VDC coil) with
>   **mechanically-linked mirror contacts integral** (IEC 60947-4-1 / -5-1) — the EDM contact is built in, no add-on aux.
> - **E-stop is now the owner's AvidCNC station** (Schneider mushroom operator + **2× ZB2-BE102 positive-opening N.C.**,
>   M12 4-pin, yellow CM12 enclosure), verified direct-opening and sound — replaces the Eaton E22 assembly.
> - **Feed-lever prox is the owner's P&F NBN8-12GM50-E0-V1** — an **NPN-NO** unit (10–30 V, M12, 8 mm non-flush).
>   Because it's NPN it lands on a **sourcing input common** (see §4); the C2-14D1's two isolated 4-point commons make
>   this clean without disturbing the +24-fed contacts.
> - **24 V control supply is the owner's Mean Well NDR-240-24** (10 A / 240 W). Because it can source ~10 A into a
>   fault, a **24 V bus overcurrent device** is added (§9/§10).
> - **Line reactor deleted** — optional for a single small drive on an ordinary branch; add back only on a stiff
>   supply or if overvoltage nuisance trips appear.
> - **Safety relay pinned to 440R-N23135S** (24 VDC MSR127RP, spring-clamp terminals).
> - **Pilot scheme revised (§4/§6/§7):** two lamps on the **machine front** between the travel limits — **green = "all
>   good," red = "not good"** — driven as **firmware complements** (`Y005`/`Y006`), so exactly one is lit whenever the
>   panel is powered. A **white "power on" lamp (XB4BVB1)** sits at the disconnect, fed straight off the 24 V bus.
>   The old cycle-active / amber "safety-tripped" indications are removed; the safety-relay **41-42 N.C. aux is now spare.**
> - **Wiring detailing (from the wire schedule):** the **PSU primary gets its own 2-pole ~3 A fuse** (the 35 A branch
>   can't protect the 16 AWG PSU tap; both L-N conductors are live at 208 V — 1-pole/120 V only if a neutral is run).
>   The **DB-resistor over-temp thermal switch is wired to spare input `X012`** with a fault rung (§4/§7). A **dedicated
>   PE bond to the machine frame/column** is added (do not rely on the motor mounting bolts), plus DIN-rail and
>   Contactor B frame bonds. All accessories are **home-run** to the panel — no field j-boxes. See `..._Wire_Schedule.md`.

> **Rev F changes (safety parts finalized):** safety relay confirmed as **440R-N23135** (MSR127RP,
> **24 V DC** supply — not the 115/230 VAC N23134/N23133). Output allocation set: 13-14 → Contactor A
> coil, 23-24 → STO, 33-34 → `X011` (fail-safe N.O., no ladder change), 41-42 aux → "SAFETY TRIPPED"
> lamp. Operator devices (DRILL/TAP selector, reset, pilot lamps) now come **from the owner's 22 mm
> stock** — parts to be identified in the shop; E-stop may also be from stock if direct-opening and
> dual-N.C.-capable. *(Rev G supersedes the 41-42 → amber lamp allocation; see above.)*

> **Rev E changes (safety confirmed):** safety relay is an **AB Guardmaster MSR127RP** (monitored
> reset + EDM, ≥3 N.O. outputs → Contactor A coil + VFD STO1 + STO2). E-stop is an **Eaton E22LTA2QB**
> (EN 418, DEMKO, direct-opening) + **E22B1** second N.C. for dual channel + **E22VA8** yellow legend.
> Contactor A confirmed as a **mirror-contact (mechanically-linked) contactor** — required for valid
> EDM. STO wired dual-channel (remove the GS20 STO jumper). Clarified that the IDEC **RF1V** is a
> force-guided relay component, not an MSR127 alternative (optional fan-out / discrete-build only).
> *(Rev G supersedes the Eaton E-stop with the owner's AvidCNC/Schneider station, and names Contactor A
> as the WEG CWBS12 safety contactor.)*

> **Rev D changes (control & logic confirmed):** PLC is a **CLICK PLUS C2-01CPU-2** (no built-in I/O)
> with **two C2-14D1** option modules (16 in / 12 out) — inputs sink/source-selectable, C2-14D1 outputs
> sinking (NPN) so GS20 DIs set to source mode. Interposing relay **CR-B = Murrelektronik 52102** (24 VDC
> coil, DPDT, 6 A/250 VAC); land the Furnas theater coil on its 240 V tap. Added CPU battery (D0-MC-BAT)
> and USB programming cable; CLICK software is a free v3.00+ download.

> **Rev C changes (drive selection + disconnect):** VFD confirmed as **GS23-22P0** against the
> GS20(X) selection tables (CT 7.5 A ≥ 6.42 A FLA); matched accessories named — braking resistor
> **BR-N1-280W50** (50 Ω), branch fuses **3× JHL35 (Class J, 35 A)** per the drive's fuse chart.
> *(Rev G removes the optional line reactor and replaces the integrated fusible disconnect with a
> non-fused SIRCO M + separate US6J3 Class J block.)*

> **Scope of this package.** Complete control retrofit replacing the original all-line-level
> control wiring with a modern low-voltage architecture: safety relay + VFD power section +
> CLICK PLUS logic controller, in a UL 508A–style DIN-rail enclosure. The original drum switch,
> button pendant, and travel limit switches are retained and converted to 24 VDC signaling.
>
> **This is a design package, not a substitute for on-machine verification.** Field-verify every
> mechanical assumption (noted in §12), size branch protection to the *actual* VFD manual, and have
> the finished installation LOTO-validated by a qualified person before production use.

---

## 1. Design intent

The original machine ran every control conductor — drum switch, pendant, limits, contactor
coils — at 208 V line level. That is a large surface area of live wiring for a machine an operator
leans over. This retrofit accomplishes four goals stated at the outset:

1. **Kill the all-line-level hazard.** Everything a human touches (drum, pendant, limits, e-stop,
   selector) *and everything a human reads* (the machine-front pilot lamps) now runs at **24 VDC**.
   The only line-level conductors remaining are inside the enclosure between the disconnect and the motor.
2. **Add single-tap capability.** Reverse-at-bottom, stop-at-top, as a selectable software mode.
   Continuous tapping remains available as a one-rung change (§7, note C).
3. **Keep the original controls and the "chunk."** Drum switch, pendant, and limits are reused as
   24 V inputs. Both original contactors are reused — one doing real safety work, one for sound.
4. **Put the logic in software, not fixed wiring.** A CLICK PLUS PLC brokers every command; the
   sequence lives in ladder, not in relay hardwiring.

### The one rule that governs the whole design
**The PLC is not the safety system.** A standard PLC's outputs can weld and its firmware can hang.
The **E-stop and the over-travel backstop remove motor power through a hardwired safety relay that
does not depend on the controller executing code.** The PLC *sees* the safety state but is never the
thing that makes the machine safe. (This is also why the operator status lamps — which *are* firmware —
are advisory only: see §6/§7.)

### Three layers
| Layer | Trust model | What lives here |
|---|---|---|
| **Safety** | Hardwired, firmware-independent | E-stop → safety relay → drops Contactor A + opens VFD STO |
| **Logic** | CLICK PLUS PLC | DRILL/TAP modes, single-tap state machine, VFD command, preset select, status lamps |
| **Telemetry** *(optional, future)* | Read-only ESP32 | Cycle counting → Cloudflare stack. Never touches control or safety path |

---

## 2. Power topology (see DWG 01)

- Motor is wired **permanently in its 4-pole Δ (high-speed) configuration** — treat it as a plain
  3-lead 1750 RPM motor. The YY (8-pole) leads are capped but left accessible in the peckerhead.
- The **VFD synthesizes both nameplate speed ranges** through the *existing* mechanicals: 60 Hz
  reproduces the high ranges, **30 Hz reproduces the low range exactly** (the drive is doing the
  same 2:1 the pole-change used to do). At 30 Hz the drive holds V/Hz so low-range torque is full.
- The operator still moves the 2-groove belt and spins the Reeves v/s dial exactly as before; only
  "low/high" changes from a winding-swap clunk to a soft VFD preset.

> **Demolition — remove the existing front-of-machine switch.** The machine as found routes line
> from a rear entry j-box, up through an **Allen-Bradley AH7810 3-pole manual switch** on the front
> of the machine, then down to the contactor box. Confirmed on inspection to be a plain 3-pole
> switch (no overload heaters). **Delete it entirely**, along with its front-of-machine cable loop:
> it is line-level wiring in the operator's space — exactly the hazard this retrofit exists to
> remove. Feed the new enclosure **directly from the rear line-entry j-box**; the enclosure's
> disconnect becomes the **sole disconnecting means** (mount its external handle where it is readily
> reachable for LOTO). Before cutting: LOTO and meter to confirm which rear cable is the true
> incoming supply, size the run into the enclosure for VFD input + branch protection, and patch or
> repurpose the vacated front j-box location (candidate spot for the operator pendant/station).

```
208V 3PH 60Hz  ──►  MAIN DISCONNECT — non-fused rotary (Socomec SIRCO M, UL 98, 3-pole 60 A,
                    external S00 handle on a fixed enclosure wall, padlockable OFF, NO door interlock)
                    ──►  BRANCH FUSES (3× JHL35 — Class J, 35 A — in a Mersen US6J3 finger-safe block)
                    ──►  CONTACTOR A (WEG CWBS12 safety contactor, 24 VDC coil, dropped by SAFETY RELAY)
                    ──►  VFD (GS23-22P0, 2 HP / 230 V class / 3PH input)  +DB resistor, STO
                    ──►  MOTOR (permanent 4-pole Δ, 1.5 HP, 143TC, 6.42 A FLA)
```

> **Disconnect + branch protection — split, wall-mounted, no door rod (Rev G).** The integrated
> fusible disconnect of earlier revisions is replaced by two devices in series inside the enclosure:
> a **non-fused rotary switch** (Socomec SIRCO M Compact, **UL 98**, 3-pole, 60 A, 100 kA SCCR,
> load-break) followed by a **separate Class J fuse block** (Mersen **US6J3**, IP20 finger-safe,
> 60 A frame, holding the 3× **JHL35**). Order matters: **line → disconnect → fuse block → Contactor A
> → VFD**, so throwing/locking the disconnect de-energizes the fuse block for safe fuse changes.
>
> The switch is operated by an **external S00 rotary handle (Socomec 14741111, NEMA 3R/12)** mounted
> on a **fixed wall of the enclosure**, handle outside, **padlockable in OFF** for LOTO. There is
> **no through-door coupling rod** — the door interlock is intentionally omitted (the box runs
> door-open for commissioning/tuning by choice), so a door coupling would serve no purpose and only
> add alignment fuss. A fixed-wall penetration is a one-time alignment; a large switch-to-wall offset
> would need a separate extension shaft, which a compact mount avoids.
>
> **Class J frame:** the JHL35 is a 35–60 A (60 A-frame) Class J fuse, so both the block and the
> switch sit on the 60 A tier. **Live-access mitigations:** the fuse block is finger-safe (protects
> against contact during door-open tuning, when it is live); the always-critical shrouding is on the
> **disconnect's incoming line lugs**, which stay live with the disconnect OFF — confirm those are
> IP20 or fit terminal covers. No door interlock is wired to the safety relay.

> **Contactor assignment (the two units in the box).**
> - **Contactor A = WEG CWBS12-33-30C03** (line/safety), a purpose-built **IEC safety contactor**:
>   3-pole, 12 A (ample for the ~9.6 A VFD input), **24 VDC coil switched directly by the safety
>   relay**, with **mechanically-linked mirror contacts integral** (IEC 60947-4-1 / -5-1). The mirror
>   N.C. contact used for EDM is built in — no add-on aux block, and no risk of pairing a
>   non-mirror aux (e.g. a plain Fuji SC-E aux) that would invalidate the EDM.
> - **Contactor B = the vintage right-hand Furnas contactor** (theater). It switches **no load**, so
>   its only duty is mechanical armature cycling — the gentlest possible use of vintage iron, and it's
>   the unit you actually *hear*. Keep its original D2936-32 coil (the dual-voltage rating is moot
>   since it switches nothing); drive it via interposing relay CR-B on `Y004`.
> - **Remove both heaters / the overload block.** Motor overload is now the VFD's electronic thermal
>   (§5); a fixed overload downstream of a drive mis-reads PWM current and nuisance-trips. The EDM
>   contact comes from Contactor A's own mirror aux, so nothing is lost by removing the overload block.

---

## 3. Sequence of operations

### 3.1 Mode selection
A door-mounted **DRILL / TAP** selector (2-position maintained) sets `X001`/`X002`. The drum switch
(OFF / LOW / HIGH) remains the operator's speed selector and a run permissive: **OFF = no run.**

### 3.2 DRILL mode (latched, bidirectional)
Power feed is engaged by the operator (mechanical lever). The controller's job is spindle run +
direction + speed. **Forward and reverse are symmetric latched runs** (`C30` / `C31`):

1. Operator sets drum to LOW or HIGH and engages the mechanical power-feed lever.
2. Press **FWD** → spindle **latches** forward at the selected preset and runs until stopped.
   Mechanical trip + return spring perform the down-trip-retract cycle unaided.
3. Press **REV** → spindle **latches** reverse and runs until stopped. Same one-press-and-go model
   as FWD.
4. **Stop-first, opposite-as-stop.** While running one direction, pressing **STOP _or_ the opposite
   direction button stops** the run. It takes a **second press** of the opposite button to actually
   run the other way — the spindle is never plug-reversed under power. (Reversal energy, when the
   drive does ramp through zero, is bled by the DB resistor; §5.)
5. **Fault:** if the lower travel limit is reached while running **forward** in DRILL, the mechanical
   trip has failed and the quill is running to the hard end — the controller **fault-stops** and
   goes red. (In DRILL the bottom limit is a fault, not a sequence step; reverse is not a feed-down
   runaway, so the bottom-limit fault is FWD-only. A reverse over-travel into the top stop is caught
   by the VFD over-torque backstop, §5.)

### 3.3 TAP mode (single-tap, self-lead)
Power feed lever **OFF** — the tap threads itself in and self-leads; feed-per-rev auto-synchronizes
to any pitch. The controller runs the state machine; the limits sequence it.

```
IDLE ──FWD pressed──► TAP_DOWN ──bottom limit──► BACK_OUT ──top limit──► (STOP) ──► IDLE
```

- **Entry gate:** TAP mode cannot leave IDLE unless the **feed-lever-OFF proximity** proves the
  lever is disengaged. Starting a tap with power feed engaged is the tap-snapping condition.
- **Runtime trip:** the feed-lever-OFF signal is also watched *during* TAP_DOWN and BACK_OUT. If the
  lever is bumped engaged mid-cycle, the controller **fault-stops immediately** — entry-only checking
  would let a mid-cycle bump break the tap.
- Direction reversal is done **electronically by the VFD** (ramped decel-through-zero-reaccel with
  the DB resistor bleeding the reversal energy) — gentle on the tap, no contactor shoot-through.
- **Continuous mode** (future): at the top limit, re-enter TAP_DOWN instead of IDLE (§7 note C).

### 3.4 STOP vs E-STOP — two physically distinct controls
| Control | Path | Behavior |
|---|---|---|
| **STOP** (pendant) | Soft — PLC input `X004`, VFD ramp | Normal cycle stop. Gentle. Depends on firmware — *and that's fine, because it is not the safety stop.* |
| **E-STOP** (panel, mushroom) | Hard — hardwired to safety relay, **bypasses the PLC** | Drops Contactor A (power removal + chunk) and opens VFD STO (fast torque-off). Firmware-independent. |

**No auto-restart.** After E-stop or a power interruption, the safety relay requires a deliberate
monitored **RESET**, and the PLC requires a fresh FWD press. Nothing restarts on its own. In TAP,
a safety trip also drops the state machine to IDLE (§7 RUNG 13), so a reset alone never resumes a tap.

### 3.5 JOG mode (setup inching)
A **long hold of FWD (≥ 5 s)** arms jog mode. The 5 s hold is deliberately un-fakeable and the button's
duration is what selects "enter jog" vs. the normal short-press run — so FWD's short-press latch acts on
**release** (a quick tap latches a run; a 5 s hold enters jog and does *not* start a run on release).

- **In jog mode**, the pendant **FWD and REV buttons are momentary hold-to-run jogs** — the spindle turns
  only while a button is held — at a forced **30 Hz** (preset-LOW) for controllable inching, in either
  direction, gated **safe (`X011`) · no fault · no over-temp**. Normal latched runs and TAP starts are
  inhibited while armed.
- **Exit** on any of: a **short (< 5 s) STOP press**, **60 s of jog inactivity**, **any latched fault**,
  or an **E-stop / safety trip**. STOP always stops motion on press; the < 5 s qualifier only adds the
  mode-exit so a long STOP hold is a plain stop.
- **Annunciation: blinking green = JOG ARMED** (§4). Because jog is a "safe + armed" state, it lives in the
  green family; the lamp blink makes the hidden mode visible so it can't be silently forgotten.

> Jog mode is firmware, and — like the status lamps — advisory to the operator, not a safety function. The
> hardwired safety path (Contactor A drop + VFD STO) is unaffected by what mode the PLC believes it is in; an
> E-stop always wins and also force-exits jog.

---

## 4. I/O assignment (CLICK PLUS)

CLICK addressing: `X` = discrete input, `Y` = discrete output, `C` = control relay (internal bit),
`T` = timer. CLICK PLUS **CPUs have no built-in I/O**; this build uses a **C2-01CPU-2** (2 option
slots) with **two C2-14D1** option modules (each 8 DC sink/source in + 6 DC sink out) → 16 in / 12 out
for the 12 in / 6 out needed.

> **Sink/source (Rev H — simplified by the PNP prox).** The C2-14D1's **8 inputs are split into two
> isolated 4-point commons** (`X1–X4` on C1, `X5–X8` on C2 per module), each independently wire-able as
> sinking or sourcing. In Rev G the NPN prox forced one bank sourcing — but with two modules, `X009`–`X012`
> land in the *same* 4-point bank, so the NPN prox (`X010`) could not be isolated from the +24-fed contacts
> `X009`/`X011`/`X012` that shared its common. **Rev H swaps the prox to a PNP-NO unit** (P&F
> NBN8-12GM50-E2-V1), which **sources +24** on target — so it lands on the **same sinking common** (to 0 V)
> as every other dry contact. **All input commons now go to 0 V; there is no sourcing bank.** Logic sense is
> unchanged and still fail-safe: target present (lever OFF) → `X010` = 1; any break/dead sensor → `X010` = 0
> → TAP entry blocked. The **C2-14D1 outputs are sinking (NPN)**, so set the GS20 DIs to **source mode** with
> commons bonded (see §5/§10).

### Inputs
| Addr | Signal | Field device | Wiring / polarity | Used in |
|---|---|---|---|---|
| `X001` | Mode: DRILL | Door selector pos 1 (XB4BD21, N.O. block) | N.O., 1 = DRILL selected | Logic |
| `X002` | Mode: TAP | Door selector pos 2 (XB4BD21, 2nd N.O. block) | N.O., 1 = TAP selected | Logic |
| `X003` | START / FWD (+ jog-enter on long hold) | Pendant FWD button | N.O. momentary; short-press latches on **release**, ≥5 s hold arms jog | Both |
| `X004` | STOP | Pendant STOP button | **Wired N.C.**, 1 = *not* pressed (fail-safe); <5 s press also exits jog | Both |
| `X005` | REV (latched run; momentary jog in jog mode) | Pendant REV button | N.O. momentary; press latches DRILL_REV, or jogs while armed | Both |
| `X006` | Bottom travel limit | Existing Honeywell 1LS1-J (SPDT) | Wire the **N.C. side**: 1 = not at bottom; 0 = at bottom *or wire break* (fail-safe) | TAP=reverse; DRILL=fault |
| `X007` | Top travel limit | Existing Honeywell 1LS1-J (SPDT) | Wire the **N.C. side**: 1 = not at top; 0 = at top *or wire break* | TAP=stop |
| `X008` | Drum LOW | Drum switch LOW pos | N.O., 1 = LOW selected | Speed preset |
| `X009` | Drum HIGH | Drum switch HIGH pos | N.O., 1 = HIGH selected | Speed preset / permit |
| `X010` | Feed-lever-OFF proof | P&F NBN8-12GM50-E2-V1 (**PNP-NO**) on the **sinking** common | 1 = lever confirmed OFF (safe) | TAP interlock |
| `X011` | Safety-relay OK | MSR127 33-34 N.O. safety output | 1 = safety healthy (fail-safe) | Run permissive + green lamp |
| `X012` | DB-resistor over-temp | BR-N1-280W50 thermal switch | Wire the **N.C. side**: 1 = normal; 0 = over-temp *or wire break* (fail-safe) | Fault |

> Drum OFF = `X008`=0 **and** `X009`=0 → no run permissive. That reproduces the original OFF detent.
> The **1LS1-J** limits are SPDT rated 10 A line duty but only 0.8 A/115 Vdc pilot-duty; switched at
> 24 VDC into PLC inputs the load is a few mA. The **N.C.-side wiring is fail-safe** (a filming/failing
> contact drifts open = "at limit / stop" = safe direction). The spare N.O. on each switch is free —
> use it for a local indicator or a cross-check sense line.

### Outputs
| Addr | Signal | Drives | Notes |
|---|---|---|---|
| `Y001` | VFD Run-FWD | VFD DI1 | Mutually exclusive with `Y002` |
| `Y002` | VFD Run-REV | VFD DI2 | Mutually exclusive with `Y001` |
| `Y003` | VFD Preset-LOW (30 Hz) | VFD DI3 (multi-speed) | ON = low range; OFF = 60 Hz |
| `Y004` | Contactor B coil | Interposing relay CR-B → Contactor B (vintage Furnas, no load) | **Theater chunk** — pulsed on each FWD/REV transition |
| `Y005` | **GREEN lamp** | Machine-front green pilot (24 V ZBVB3) | **Solid** = all-good (`X011`∧¬`C10`∧¬`C11`∧¬`C60`); **blink** = JOG ARMED (same ∧ `C60`) |
| `Y006` | **RED lamp** | Machine-front red pilot (24 V ZBVB4) | **Solid** = safety trip or latched fault (`¬X011`∨`C10`); **blink** = DB over-temp (`C11`, when no solid-red) |

> **Pilot scheme (Rev H — four states, exactly one active).** The two machine-front lamps encode four
> operator states, in priority order (§7, RUNG 28/29). A ~1 Hz free-running blink bit (`C99`) modulates
> whichever lamp is active:
>
> | Priority | Lamp | Meaning | Condition |
> |---|---|---|---|
> | 1 | **Red — solid** | Safety tripped or latched hard fault → **investigate** | `¬X011 ∨ C10` |
> | 2 | **Red — blink** | DB resistor over-temp → **let it cool** (self-clears) | `C11 ∧ X011 ∧ ¬C10` |
> | 3 | **Green — blink** | **JOG ARMED** | `X011 ∧ ¬C10 ∧ ¬C11 ∧ C60` |
> | 4 | **Green — solid** | All-good | `X011 ∧ ¬C10 ∧ ¬C11 ∧ ¬C60` |
>
> The states are mutually exclusive and exhaustive, so **exactly one lamp is doing something** (solid or
> blinking) whenever the PLC scans. Both lamps live on the **machine front, between the travel limits**,
> run on a 24 V pair out to the machine (keeping line voltage out of the operator space). The distinct
> *blink-red vs solid-red* split matters because the operator's response differs: a thermal event is
> "wait," a hard fault is "look."
>
> The **white "power on" lamp (XB4BVB1)** is **not a PLC output** — it is wired straight across the
> protected 24 V bus by the disconnect, so it is a true "panel energized" tell independent of the
> controller.
>
> **Firmware-honesty caveat:** because green/red are firmware, a total CPU hang freezes both in their
> last state. This is acceptable **only** because the lamps (and jog mode) are advisory — the real safety
> (Contactor A drop + VFD STO) is hardwired through the safety relay and does not depend on the PLC.

> **Contactor A is NOT a PLC output.** It is owned by the safety relay only, so firmware can never
> hold the line contactor closed against a safety event.
>
> **CR-B is a power stage, not a logic stage.** All chunk *timing* is decided in the PLC on `Y004`
> (Rungs 14–15) — CR-B (24 VDC coil ← `Y004`; 6 A/250 VAC contact → Furnas coil) only amplifies that
> decision to drive the vintage AC coil. Drive CR-B's coil with a free-wheeling diode (or a suppressed
> relay variant) to protect the CLICK output; the DPDT part leaves a spare pole for a telemetry tap.

### Internal bits / timers
| Addr | Meaning |
|---|---|
| `C1` | State IDLE (derived: TAP mode ∧ ¬C2 ∧ ¬C3 ∧ ¬fault) |
| `C2` | State TAP_DOWN (latched) |
| `C3` | State BACK_OUT (latched) |
| `C10` | FAULT — latched hard fault (manual clear via RUNG 11) |
| `C11` | THERMAL — DB over-temp, **self-clearing** (follows `X012` with cool-down delay); inhibits run, drives blink-red |
| `C20` | RUN_PERMIT (`X011 ∧ (X008∨X009) ∧ X004 ∧ ¬C10 ∧ ¬C11`) |
| `C30` | DRILL_RUN — forward latch |
| `C31` | DRILL_REV — reverse latch (**new**) |
| `C40` | Chunk-pulse request |
| `C50` | FWD-press consumed flag (long-hold-entered-jog **or** press-that-stopped-REV → suppress release-latch) |
| `C60` | JOG_MODE armed (**new**) |
| `C99` | ~1 Hz free-running blink bit (indicator modulation) |
| `T1` | Chunk pulse timer (300 ms) |
| `T5FWD` | FWD hold timer (5 s → arm jog) |
| `T5STP` | STOP hold timer (5 s → distinguishes short-exit from long-stop, jog mode) |
| `T60` | Jog inactivity timer (60 s → auto-exit) |
| `Tcool` | DB-resistor cool-down delay (self-clear `C11` after `X012` recovers) |
| `Tb1`/`Tb2` | Blink astable (500 ms / 500 ms → `C99`) |

---

## 5. VFD configuration

**Selected drive: AutomationDirect GS23-22P0** (2 HP, 230 V class, 3-phase input; frame B). Confirmed
against the GS20(X) selection tables: 200–240 VAC 3-phase input covers 208 V; **CT rated output
7.5 A ≥ 6.42 A motor FLA**. Catalog data used elsewhere in this package: input current 9.6 A, fuse
**JHL35 (Class J, 35 A)** or **TJN35 (Class T, 35 A)** per the drive's fuse chart — **this build uses
JHL35 (Class J)** to match the US6J3 block, braking resistor min 47.5 Ω → **BR-N1-280W50**, heat
**74.3 W total**, clearances 50 mm top/bottom · 30 mm sides. (The optional input **line reactor is
deleted in Rev G**.) Built-in features this design relies on: **STO (TÜV/SIL2)**, **over-torque
detection**, **16-step speed**, **7 DI (24 V, NPN/PNP-selectable)**. Set the following (parameter
numbers per the GS20(X) manual):

| Function | Setting | Why |
|---|---|---|
| Motor rated current | **6.42 A** (nameplate FLA) | Enables the drive's electronic thermal overload — replaces the original heaters |
| Motor rated freq / voltage | 60 Hz / 208 V | Base point for V/Hz |
| Command source | External terminals (DI) | PLC brokers all commands |
| Frequency source | Preset / multi-speed via DI | `Y003` selects 30 Hz preset vs 60 Hz main |
| Main frequency | 60 Hz (HIGH range) | Reproduces the high ranges through the belts |
| Preset 1 frequency | **30 Hz** (LOW range) | Exactly reproduces the low range |
| DI1 / DI2 / DI3 | Run-FWD / Run-REV / preset-1 | ← `Y001` / `Y002` / `Y003` |
| Accel / decel + S-curve | Tuned, S-curve ON | Soft start; gentle self-lead reversal |
| Braking (DB) | Enable chopper; DB resistor on `+`/`BR` | Bleed reversal energy so REV doesn't overvolt-trip |
| STO | Wired to safety relay 23-24 (jumper removed) | Fast torque-off; belt-and-suspenders with Contactor A |
| **Over-torque / stall detection** | **Enable; level just above real tapping torque; short trip delay; action = trip/fault; active 30–60 Hz** | **The functional backstop for a jam** — catches a "failed to reverse/stop" stall independent of the PLC |
| DI sink/source | **Source mode** (match sinking CLICK outputs) | Electrical compatibility |

> **Sink/source:** C2-14D1 outputs are sinking (NPN) → set the GS20 DIs to **source mode** and bond
> CLICK 0 V to the GS20 DCM. Align before power-up.

---

## 6. Safety system (see DWG 02)

**Device:** **AB Guardmaster MSR127RP — cat # 440R-N23135S** (24 V DC supply, spring-clamp terminals,
monitored manual reset + EDM, **3 N.O. safety + 1 N.C. aux**, Cat 4 / PLe / SIL CL3). *(The base
-N23135 is the screw-terminal variant; the `S` denotes spring-clamp — identical relay and ratings.)*

**E-stop:** the **owner's AvidCNC station** — a Schneider mushroom **operator** with **2× ZB2-BE102**
N.C. blocks (verified **direct/positive-opening** per IEC 60947-5-1, genuine branding, sound
mechanism), an **M12 4-pin** lead, in a **yellow CM12** polycarbonate enclosure. This replaces the
Eaton E22 assembly of earlier revisions; it is the **sole safety input**.

### Safety inputs (series, both channels)
- **E-stop** — 4-wire dual-channel mushroom, maintained, twist-release. **Sole safety input.**

> **No door interlock in the safety loop — intentional.** The disconnect handle is on a fixed wall,
> not the door, and the door interlock is omitted so the machine can run door-open (§2). No
> disconnect/door interlock is wired to the safety relay; the E-stop is the only safety input.

> **No over-travel safety switch — the correct answer, not a compromise.** In TAP mode the bottom
> limit `X006` is struck on **every** cycle as the reversal trigger, so a hardwired trip there would
> drop the machine on every tap. The depth rod has a **chunky metal end stop** at the bottom of
> travel and the bottom tag is already at the end of usable rod travel, so there is physically no
> over-travel region for such a switch. Travel is **positively bounded by the mechanical stop**
> (metal-on-metal, load on the rod — *not* on a limit-switch lever). The residual "controller failed
> to reverse/stop" fault manifests as a **stall** (a *torque* event), covered by **VFD over-torque
> detection** (§5) independent of the PLC, plus the E-stop. Set the mechanical stop to engage before
> the switch levers reach their internal over-travel limit, both directions.

### Safety outputs (3 N.O. safety + 1 N.C. aux)
1. **13-14 → Contactor A coil (24 VDC).** Switches the CWBS12's 24 VDC coil directly on the DC
   control bus. Category-0 mechanical power removal, and the *session* chunk (once at start-up, once
   at shutdown/E-stop — **not** per-operation; that's Contactor B's job).
2. **23-24 → VFD STO** (STO1 + STO2). Remove the GS20's factory STO-to-+24 V jumper and route STO
   through this contact — torque removed in milliseconds without waiting for the contactor.
   **STO single-sourced by design (Rev H note):** both STO1 and STO2 are fed from the *single* output
   pair 23-24, so a welded 23-24 contact would defeat both STO channels at once — this is accepted
   because **Contactor A (13-14) is the diverse, independent stop channel** (mechanical Cat-0 power
   removal) and the CWBS12 **mirror contact catches a welded A via EDM**, blocking reset. The system's
   redundancy therefore lives in the contactor + EDM path, not in STO's own two channels. (The MSR127
   has only three N.O. outputs — A-coil, STO, `X011` — so splitting STO across two outputs isn't
   available without giving up the contactor drive or the PLC's safety-state sense.)
3. **33-34 → PLC `X011`** ("safety OK"). N.O., closed when the relay is running → `X011` = 1 when
   safe. Keeps the ladder's fail-safe sense unchanged (a broken wire reads "not safe"). `X011` is
   also what makes the **green** operator lamp honest — green drops the instant safety trips.
4. **41-42 (N.C. aux) → spare (Rev G).** Previously drove an amber "SAFETY TRIPPED" lamp; with safety
   state now shown through the firmware green/red lamps, this aux is **unused**. Leave landed on a
   labeled terminal for future use (e.g. telemetry "safety tripped" flag).

> Confirm the safety relay's output rating covers the CWBS12 coil inrush (it does). Going 24 VDC on
> the coil keeps line-adjacent voltage off the coil run entirely.

### Monitoring
- **Monitored manual reset** (`S33`-`S34`): a deliberate RESET press (XB4BA21, N.O. momentary) is
  required after any safety event or power restore → **no auto-restart**.
- **EDM / external device monitoring:** the CWBS12's **integral mirror / mechanically-linked N.C.
  contact** goes into the reset loop so a *welded* Contactor A prevents reset — the safety system
  detects its own output failure. (The CWBS12 is a safety contactor precisely so this mirror contact
  is a certified, trustworthy part with no add-on aux.)
- **Safety state to PLC (`X011`) ← 33-34 N.O.:** the PLC knows the safety state (permissive) but has
  no authority over it. N.O. output = fail-safe sense (1 when running).

> The sequencing travel limits `X006`/`X007` do **not** go to the safety relay — in TAP mode,
> hitting them is normal operation. The safety string is **E-stop only**; over-travel/stall is handled
> mechanically + by the VFD.

---

## 7. Ladder logic — CLICK PLUS (see DWG 05)

Transcribe into the free **CLICK Programming Software**. Symbols:
`─] [─` N.O. · `─]/[─` N.C. · `─]↑[─` leading-edge (press) · `─]↓[─` trailing-edge (release) ·
`─( )─` OUT · `─(S)─` SET · `─(R)─` RST · `[TMR …]` timer.

> **Scan order is load-bearing in Rev H.** The bidirectional stop-first behavior and the jog-mode
> short-press logic depend on rungs executing in the order listed. Two rules to preserve: (a) the DRILL
> **latch-SET** rungs (4, 5) run **before** the **opposite-stop** rung (7); (b) the jog/consume flag `C50`
> is set before the FWD **release-latch** is evaluated. Transcribe in the numbered order and don't reorder.

```
RUNG 1 · RUN PERMISSIVE → C20      (safe · drum-not-OFF · STOP-not-pressed · no fault · no over-temp)
   X011      X004       C10       C11
 ──] [───┬──] [───────]/[───────]/[──────────────( )── C20  RUN_PERMIT
   X008  │  STOP(nc=1) noFault   noTherm
 ──] [───┤ (drum LOW ─ OR)
   X009  │
 ──] [───┘ (drum HIGH)

RUNG 2 · SPEED PRESET → Y003       (drum LOW → 30 Hz; jog forces LOW)
   X008
 ──] [───┬───────────────────────────────────────( )── Y003  PRESET_LOW
   C60   │ (jog armed → force 30 Hz)
 ──] [───┘

RUNG 3 · BLINK ASTABLE → C99       (~1 Hz; or substitute a CLICK built-in clock relay)
   C99
 ──]/[──────────────────────────────[TMR  Tb1  K500ms]
   Tb1
 ──] [─────────────────────────────────────────────(S)── C99
   C99
 ──] [──────────────────────────────[TMR  Tb2  K500ms]
   Tb2
 ──] [─────────────────────────────────────────────(R)── C99

────────────────────────────────  DRILL — latched, bidirectional  ────────────────────────────────

RUNG 4 · DRILL FWD — LATCH SET on RELEASE   (short tap latches; ¬C50 = not consumed by a long-hold/opposite-stop; ¬C60 = not in jog)
   X001      X003      C50       C60       C20       C10       C31
 ──] [─────]↓[──────]/[───────]/[───────] [───────]/[───────]/[──(S)── C30  DRILL_RUN
          release  ¬consumed  ¬jog     permit   noFault   ¬REV

RUNG 5 · DRILL REV — LATCH SET on PRESS      (mirror of FWD; no long-hold role, so acts on press)
   X001      X005      C60       C20       C10       C30
 ──] [─────]↑[──────]/[───────] [───────]/[───────]/[──────────(S)── C31  DRILL_REV
          press    ¬jog      permit   noFault   ¬FWD

RUNG 6 · DRILL — LATCH RESET   (stop / not DRILL / lost permit / fault → drop both)
   X004
 ──]/[───┬───────────────────────────────┬───────(R)── C30
   X001  │                                └───────(R)── C31
 ──]/[───┤ (¬DRILL)
   C20   │ (¬permit — incl. X011 safety, drum-OFF, over-temp)
 ──]/[───┤
   C10   │ (fault)
 ──] [───┘

RUNG 7 · OPPOSITE-AS-STOP   (opposite button = stop only; runs AFTER the SET rungs)
   X005      C30
 ──]↑[──────] [────────────────────────┬─(R)── C30      REV press stops a FWD run
                                        └─(S)── C50      …and consume, so its release can't latch REV path
   X003      C31
 ──]↑[──────] [────────────────────────┬─(R)── C31      FWD press stops a REV run
                                        └─(S)── C50      …and consume, so its RELEASE can't latch FWD
   (Why it works: RUNG 5's ¬C30 / RUNG 4's ¬C31 interlocks block the opposite latch on the *same* press
    because the running latch is still set when SET evaluates; RUNG 7 then drops it. Second press latches.)

RUNG 8 · CLEAR FWD-CONSUMED ON RELEASE
   X003
 ──]/[─────────────────────────────────────────────(R)── C50

RUNG 9 · DRILL BOTTOM-LIMIT FAULT   (FWD only; reverse is not a feed-down runaway)
   X001       C30        X006
 ──] [──────] [───────]/[─────────────────────────(S)── C10  FAULT

────────────────────────────────  TAP — single-tap state machine  ────────────────────────────────

RUNG 10 · TAP START (IDLE → TAP_DOWN)   entry gate: lever OFF (X010=1), not in jog
   X002     X003     X010     C60      C20      C10      C2       C3
 ──] [────]↑[─────] [─────]/[─────] [─────]/[─────]/[─────]/[──(S)── C2  TAP_DOWN
                          ¬jog     permit  noFault

RUNG 11 · TAP DOWN → BACK_OUT   (bottom limit)
   C2         X006
 ──] [──────]/[─────────────────────────┬────────(R)── C2
                                         └────────(S)── C3  BACK_OUT

RUNG 12 · TAP BACK_OUT → IDLE   (top limit)      [note C: SET C2 here for continuous]
   C3         X007
 ──] [──────]/[───────────────────────────────────(R)── C3

RUNG 13 · TAP ABORT   (stop / not TAP / fault / lost-permit-or-safety)   ← Rev H: adds ¬C20 leg
   X004
 ──]/[───┬───────────────────────────────┬───────(R)── C2
   X002  │                                └───────(R)── C3
 ──]/[───┤ (¬TAP)
   C10   │ (fault)
 ──] [───┤
   C20   │ (lost permit — incl. E-stop/safety via X011, drum-OFF, STOP)
 ──]/[───┘

RUNG 14 · TAP FEED-LEVER RUNTIME TRIP   (lever ON during a cycle = tap-snap)
   C2         X010
 ──] [───┬──]/[───────────────────────────────────(S)── C10  FAULT
   C3    │ LeverON
 ──] [───┘

────────────────────────────────  DB over-temp — self-clearing  ────────────────────────────────

RUNG 15 · DB OVER-TEMP SET   (X012=0 = over-temp OR wire break → assert immediately)
   X012
 ──]/[─────────────────────────────────────────────(S)── C11  THERMAL

RUNG 16 · DB COOL-DOWN → SELF-CLEAR   (clears only after X012 stays normal for the cool-down delay)
   X012
 ──] [──────────────────────────────[TMR  Tcool  K10000ms]
   Tcool
 ──] [─────────────────────────────────────────────(R)── C11
   (Self-clearing: no manual reset, and C11 is NOT the operator-clearable C10 — so it can't fight RUNG 17.)

RUNG 17 · FAULT RESET   (STOP while fully stopped clears the hard-fault latch)
   X004      C2        C3        C30       C31
 ──]/[─────]/[──────]/[──────]/[──────]/[──────────(R)── C10  FAULT

────────────────────────────────  JOG mode  ────────────────────────────────

RUNG 18 · FWD HOLD TIMER   (times how long FWD is held)
   X003
 ──] [──────────────────────────────[TMR  T5FWD  K5000ms]

RUNG 19 · ENTER JOG   (FWD held ≥5 s, safe, not already armed; consume the press so release won't latch a run)
   T5FWD     C50       C60       X011      C10
 ──] [─────]/[───────]/[───────] [───────]/[──────┬─(S)── C60  JOG_MODE
                                                  └─(S)── C50  (consumed)

RUNG 20 · JOG IDLE TIMEOUT   (60 s with no jog button → auto-exit)
   C60      X003      X005
 ──] [────]/[──────]/[──────────────[TMR  T60  K60000ms]
   T60
 ──] [─────────────────────────────────────────────(R)── C60

RUNG 21 · JOG FORCE-EXIT   (any latched fault or safety trip)
   C10
 ──] [───┬─────────────────────────────────────────(R)── C60
   X011  │
 ──]/[───┘ (¬safe → E-stop / safety trip)

RUNG 22 · STOP HOLD TIMER (jog)
   C60       X004
 ──] [─────]/[──────────────────────[TMR  T5STP  K5000ms]

RUNG 23 · SHORT-STOP EXIT (jog)   (STOP released before 5 s → exit; long hold = plain stop)
   C60       X004      T5STP
 ──] [─────]↑[───────]/[───────────────────────────(R)── C60
          STOP released  ¬(was long hold)

────────────────────────────────  VFD run outputs  ────────────────────────────────

RUNG 24 · VFD RUN-FWD → Y001
   C30        C20       Y002
 ──] [───┬──] [──────]/[──────────────────────────( )── Y001  VFD_FWD
   C2    │  (normal: DRILL_RUN or TAP_DOWN)
 ──] [───┤
   C60   │  X003      X004     X011     C10      C11      Y002
 ──] [───┴─] [──────] [──────] [──────]/[─────]/[─────]/[──   (jog-FWD: armed · held · STOP-clear · safe · no fault/therm)

RUNG 25 · VFD RUN-REV → Y002
   C31        C20       Y001
 ──] [───┬──] [──────]/[──────────────────────────( )── Y002  VFD_REV
   C3    │  (normal: DRILL_REV or TAP back-out)
 ──] [───┤
   C60   │  X005      X004     X011     C10      C11      Y001
 ──] [───┴─] [──────] [──────] [──────]/[─────]/[─────]/[──   (jog-REV)

────────────────────────────────  Chunk (Contactor B, theater)  ────────────────────────────────

RUNG 26 · CHUNK REQUEST   (edge of entering any run / direction — TAP or DRILL)
   C2
 ──]↑[───┬────────────────────────────────────────(S)── C40  CHUNK_REQ
   C3    │
 ──]↑[───┤
   C30   │
 ──]↑[───┤
   C31   │
 ──]↑[───┘

RUNG 27 · CHUNK TIMER + OUTPUT
   C40
 ──] [──────────────────────────────[TMR  T1   K300ms]
   C40        T1
 ──] [──────]/[────────────────────────────────────( )── Y004  CONTACTOR_B
   T1
 ──] [─────────────────────────────────────────────(R)── C40

────────────────────────────────  Indicators (4 states, exactly one active)  ────────────────────────────────

RUNG 28 · GREEN → Y005      (solid = all-good; blink = jog armed)
   X011       C10       C11       C60
 ──] [──────]/[──────]/[──────]/[─────────────────( )── Y005  GREEN
   X011  │   C10       C11       C60       C99
 ──] [───┴─]/[──────]/[──────] [──────] [──   (jog: blink via C99)

RUNG 29 · RED → Y006        (solid = safety/hard fault; blink = over-temp)
   X011
 ──]/[───┬─────────────────────────────────────────( )── Y006  RED
   C10   │ (¬safe OR fault → solid)
 ──] [───┤
   C11   │ X011      C10       C99
 ──] [───┴─] [──────]/[──────] [──   (over-temp: blink via C99, only when no solid-red)
```

### Ladder notes
- **Note A — force LOW in TAP (optional).** Rung 2 already `Y003 = X008 ∨ C60` for jog. To also force LOW in
  every TAP cycle, add `∨ C2 ∨ C3`. Left off so the drum is honored in TAP.
- **Note B — FWD/REV interlock.** Rungs 24/25 each carry the other output's N.C.; the drive ramps through zero
  on reversal, so no PLC dead-time is required. Direction *changes* in DRILL are stop-first (RUNGs 5/6/7), so
  the interlock only ever guards simultaneous-edge corner cases.
- **Note C — continuous tapping.** In Rung 12 also `SET C2` when it `RST C3` (top → back down). One rung.
- **Note D — first scan.** IDLE is derived and every latch (`C2 C3 C10 C11 C30 C31 C60`) comes up cleared, so
  the machine powers up stopped, out of jog, and valid — no init rung.
- **Note E — max-dwell watchdog (optional).** Time `C2`/`C3`; if a state overruns its limit, `SET C10`.
  Backstops the VFD over-torque trip and E-stop; does not replace them.
- **Note F — `C50` is a shared "this FWD press is spent" flag.** It is set either when a 5 s hold enters jog
  (RUNG 19) or when a FWD press is used to stop a running REV (RUNG 7). Either way the FWD **release** in RUNG 4
  sees `C50=1` and does not latch a forward run. It clears on release (RUNG 8). This is what makes "hold-to-jog"
  and "opposite-as-stop" coexist on the one FWD button without a stray run.
- **Note G — blink source.** RUNG 3 is a portable 1 Hz astable. If you prefer, CLICK PLUS exposes a built-in
  clock-pulse relay you can use for `C99` instead and delete RUNG 3.
- **Note H — jog is advisory.** Nothing in the jog rungs touches the safety path. An E-stop opens STO and drops
  Contactor A regardless of mode, and RUNG 21 force-exits jog on the resulting `¬X011`.

---

## 8. Bill of materials

Maintained as a separate, orderable document: **`Powermatic_1200_Retrofit_BOM.md`** (grouped by
subsystem; VENDOR / PART NO / UNIT + LINE cost; owner-supplied items tagged **GBB** at $0). Keep it in
sync with this document's revision. Rev G highlights: SIRCO M 22013006 + 14741111 handle + US6J3
block, CWBS12-33-30C03 contactor, NDR-240-24, 24 V bus protection, XB4BVB1 white pilot, line reactor
removed, E-stop/prox/operator devices from inventory. **Rev H: prox → PNP NBN8-12GM50-E2-V1; DB-resistor
and Contactor-A prices corrected (+~$190 total); no new hardware from the logic changes.**

---

## 9. Wire numbering & color scheme (NFPA 79)

| Color | Circuit |
|---|---|
| **Black** | Line power (208 V, ungrounded, disconnect-controlled) |
| **Red** | AC control ≤120 V (largely N/A here) |
| **Blue** | DC control (24 VDC) — including the machine-front green/red pilots and the white power-on lamp |
| **Orange** | **Live with the main disconnect OFF** — design goal is that nothing is orange. Contactor A's coil is 24 VDC (blue); the only line-voltage coil is Contactor B's Furnas coil (theater), fed **downstream of the disconnect** so it de-energizes on LOTO. The disconnect's own incoming line lugs are inherently live with the switch OFF — shroud them (IP20), do not run them as general orange wiring |
| **White** | Grounded (neutral) conductor, if present |
| **Green / green-yellow** | Equipment grounding (PE) |

**Wire numbering:** number every conductor uniquely (both ends); land power on one duct run and 24 V
control on another; keep VFD output (U/V/W, motor cable) segregated and shielded, shield landed at the
drive end only. Run the **machine-front green/red pilots** as a 24 V pair out to the machine on the
control scheme (blue). **24 V bus overcurrent** (§10) sits at the supply output; the **PSU primary** gets
its own 2-pole ~3 A fuse (16 AWG tap can't be protected by the 35 A branch). All field accessories are
**home-run** to the panel — no machine j-boxes. **PE bond** the enclosure, back panel, door (bonding
strap), disconnect, both contactor frames, DIN rail, VFD PE, and — with a **dedicated bonding conductor,
not the motor mounting bolts** — the **machine frame/column**, all to a common ground bus.

---

## 10. Commissioning & validation checklist

**Before first power-up**
- [ ] Continuity/insulation check all power conductors; verify no line-level wire reaches any operator control or the machine-front lamps.
- [ ] Confirm branch fuses are **3× JHL35 (Class J, 35 A)** in the US6J3 block; upstream wall branch intact.
- [ ] Confirm disconnect wiring order: **line → SIRCO → US6J3 → Contactor A → VFD**; disconnect line-side lugs are shrouded/finger-safe (live with disconnect OFF).
- [ ] **24 V bus protection** landed at the NDR-240-24 output (≈5 A main + a dedicated feed for the safety relay).
- [ ] **PSU primary protection** landed — 2-pole ~3 A on the 208 V L-N feed (or 1-pole/120 V if a neutral is run).
- [ ] Confirm 24 V field polarity per §4; **prox is PNP-NO on the sinking input common** (BN→+24, BU→0V, BK→`X010`), sharing the single sinking common with all +24-fed contacts.
- [ ] PE bonding verified end-to-end (< 0.1 Ω to ground bus), including a **dedicated bond to the machine frame/column** (not via motor bolts), plus DIN-rail, disconnect, VFD, both contactors, door braid, panel, and enclosure.
- [ ] Live-access review: no door interlock (handle is wall-mounted, not on the door); door-open live work is for qualified persons only.

**Mechanical**
- [ ] Depth-rod **metal end stop** takes the bottom load — rod lands on the stop, **not** a limit lever.
- [ ] Set the stop first, then bottom/top tags **slightly shy** of it (both directions).

**VFD setup (motor uncoupled if practical)**
- [ ] Enter motor FLA 6.42 A; enable electronic thermal overload.
- [ ] 60 Hz main, 30 Hz preset-1; verify `Y003` selects 30 Hz.
- [ ] Accel/decel + S-curve; enable DB chopper; confirm DB resistor wired, including its **over-temp thermal switch to `X012`** (N.C.; open = fault). Verify a forced-open reads a fault.
- [ ] **Enable over-torque/stall detection**; level just above real tapping torque, short trip delay, active 30–60 Hz; verify a deliberate jam trips to fault.
- [ ] **Sink/source:** GS20 DIs set to **source mode**; bond CLICK 0 V to GS20 DCM.
- [ ] Jog FWD — verify spindle direction (swap two VFD *output* leads if reversed, never input).

**Contactor wiring**
- [ ] Both overload heaters removed; motor phases run straight through.
- [ ] **Contactor A = CWBS12**, 24 VDC coil switched by the safety-relay output; verify clean pull-in/drop-out.
- [ ] CWBS12 **integral mirror N.C.** landed in the EDM/reset loop.
- [ ] Contactor B = vintage Furnas, coil via CR-B, **contacts switching no load**.

**Safety validation (the part that keeps you alive)**
- [ ] E-stop pressed → Contactor A drops (audible chunk) **and** VFD STO opens; motor stops.
- [ ] Reset required to restart (no auto-restart); cycle power → machine comes up stopped.
- [ ] **EDM test:** jumper Contactor A closed (simulate weld) → safety relay refuses to reset.
- [ ] Confirm `X011` reflects safety state at the PLC.

**Indicator validation (Rev H — four states, exactly one active)**
- [ ] Powered + safe + no fault + not jogging → **green solid** (red off).
- [ ] Arm jog (hold FWD ≥5 s) → **green blink**; exit jog → back to green solid.
- [ ] Force DB over-temp (open `X012`) → **red blink**; restore + wait cool-down → self-clears to green.
- [ ] E-stop / drop `X011`, or latch a hard fault (`C10`) → **red solid** (outranks all).
- [ ] With over-temp AND a hard fault both active → **red solid** wins (priority order holds).
- [ ] Confirm **never two lamps at once, never neither** while powered.
- [ ] **White lamp** on whenever the disconnect is closed and 24 V is up, independent of the PLC.

**Sequence validation — DRILL (bidirectional)**
- [ ] FWD press → latched forward run at drum speed; STOP → ramps down.
- [ ] REV press → latched reverse run; STOP → ramps down. (Same one-press-and-go as FWD.)
- [ ] **Stop-first:** while running FWD, a REV press **stops** (does not reverse); a **second** REV press
      then runs reverse. Mirror-check FWD-stops-REV.
- [ ] Rapid opposite tap never plug-reverses under power; no stray run from the FWD release after an
      opposite-stop (verifies the `C50` consume path, RUNG 7/8).
- [ ] Bottom limit while running **forward** → fault + red solid. Running **reverse** into the top stop →
      VFD over-torque trips (not a ladder fault).

**Sequence validation — TAP**
- [ ] Entry gate: lever engaged (prox = lever ON) → FWD does **not** start a cycle.
- [ ] Cycle: lever OFF, FWD → down → bottom limit → ramped reverse → top limit → stop.
- [ ] Runtime trip: bump lever engaged mid-cycle → immediate fault-stop.
- [ ] **No auto-restart:** E-stop mid-cycle, then reset → machine stays stopped in IDLE; a **fresh FWD press**
      is required to start a new cycle (verifies RUNG 13 `¬C20` abort).

**Sequence validation — JOG mode**
- [ ] Hold FWD ≥5 s → **green blink** (armed); a normal FWD tap does **not** enter jog.
- [ ] In jog: FWD and REV are momentary hold-to-run at ~30 Hz, both directions; release → stops.
- [ ] Exit on: short (<5 s) STOP press; 60 s idle; any fault; E-stop. Long STOP hold = plain stop, stays armed.
- [ ] While armed, normal latched runs and TAP starts are inhibited.

**Chunk**
- [ ] Contactor B fires ~300 ms on each run start / direction change (DRILL and TAP); Contactor A does **not**
      cycle per-operation.

---

## 11. File index

| File | Contents |
|---|---|
| `Powermatic_1200_Retrofit_Documentation.md` | This document — design intent, architecture, sequence, I/O, VFD config, safety, ladder (§7), wiring, commissioning |
| `Powermatic_1200_Retrofit_BOM.md` | Bill of materials (VENDOR / PART NO / UNIT + LINE cost; GBB = owner-supplied) |
| `Powermatic_1200_Retrofit_Wire_Schedule.md` | Wire schedule — 96 conductors, from/to, color, gauge, stranded; ferrule = wire no.; all home-run |
| `01_power_one_line.svg` | Power one-line (Rev H) — SIRCO M non-fused rotary + US6J3 Class J block; wall-mount handle; CWBS12 24 VDC Contactor A; line reactor removed; PSU primary 2-pole fuse |
| `02_safety_loop.svg` | Dual-channel safety loop (Rev H) — E-stop = AvidCNC/ZB2-BE102 station; Contactor A = CWBS12, **24 VDC coil**, integral mirror aux in EDM; 41-42 spare; STO single-sourced note |
| `03_plc_io_wiring.svg` | CLICK terminal wiring (Rev H) — `X010` prox **PNP on the sinking common**; `X011`←**33-34**; `X012` DB over-temp; sinking outputs; green/red machine-front with blink legend; white lamp on 24 V bus; 24 V bus fuse |
| `04_panel_layout.svg` | Back-panel layout (Rev H) — SIRCO + US6J3 + wall-mount handle; **NDR-240-24**; CWBS12; 24 V + PSU-primary fuse holders; green/red **on the machine**; E-stop station off-panel; white pilot by the disconnect |
| `05_ladder_logic.svg` | Ladder render (Rev H) — bidirectional latched DRILL (stop-first), jog mode, self-clearing thermal, four-state indicators; authoritative listing in §7 |

---

## 12. Assumptions to field-verify (from remote inspection)

1. **Feed-lever prox mounting (`X010`).** Sense the **power-feed engagement lever** in its **OFF
   detent** with the M12 prox on an L-bracket off the head casting; target a ferrous flat/tab on the
   engagement shaft. Rev H uses the **PNP-NO** NBN8-12GM50-E2-V1 on the **sinking input common** (§4):
   `X010` = 1 = target present = lever OFF = safe. If the natural target is non-ferrous or dirty, add a
   steel flag or fall back to a sealed roller-lever switch (same `X010` point).
2. **Mechanical end stop set correctly.** The depth rod's metal bottom stop takes the over-travel
   load — set it to engage *before* the 1LS1-J levers reach their internal limit, both directions;
   tags slightly shy of the stop (§6, §10).
3. **AH7810 removed.** Front-of-machine 3-pole switch and its cable loop deleted; enclosure fed
   directly from the rear line-entry j-box; enclosure disconnect (SIRCO M) is the sole disconnecting
   means. Prove incoming-supply direction before re-landing.
4. **Only two feed-per-rev values** exist (the 2-groove belt positions). If more exist, self-lead
   tapping is unaffected (tap sets its own feed/rev).
5. **Power feed direction follows motor direction** (feed worm on the v/s drive shaft, upstream of
   the spindle reduction) — basis for "controller commands motor only; feed follows."
6. **Contactor B coil is 220 V** and pulls in reliably on 208 phase-to-phase (≈5% low, within pickup).
7. **Return-spring dial (4–12)** is counterbalance/retract preload; tune empirically for self-lead
   tapping — light enough not to oppose the tap pulling in, enough to assist back-out.
8. **Disconnect handle mounting (Rev G).** Confirm the S00 handle (14741111) mates the 22013006 frame
   and that the switch-to-wall offset is short enough for a direct external handle (no extension shaft).
9. **Machine-front lamp mounting (Rev G).** Confirm a spot between the travel limits for the green/red
   22 mm pilots (small bracket or two holes), reachable in the operator's line of sight, with a 24 V
   pair routed from the enclosure.

---

*End of document — GoodBetterBestCo, rev G, 2026-07-18.*

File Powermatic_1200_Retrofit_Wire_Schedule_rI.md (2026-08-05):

# Powermatic 1200 Retrofit — Wire Schedule
*Revision I · all-new wire · number each conductor at both ends (ferrule = wire no.)*

> **Rev H change (prox NPN → PNP).** The feed-lever prox is now a **PNP-NO** unit (P&F NBN8-12GM50-E2-V1). It
> sources +24 to `X010` on target, so it lands on the **sinking** input common like every other +24-fed contact —
> the dedicated sourcing common of Rev G is deleted. Only the PLC-input common wiring changes (rows 57 / 72 / 75);
> all other conductors are unchanged from Rev G. Ladder/indicator changes in Rev H are firmware-only (no new wire).

> **Rev I changes (fusing + GS20 DI + fan).**
> 1. **Row 77 deleted.** The GS20 DIs run in **NPN (sink) mode with internal power** — the drive's factory-default
>    switch position. The CLICK's sinking outputs pull DI1–DI3 to 0 V and the only common conductor is row 81
>    (CLICK 0 V → DCM). **Never land +24 V on DCM**: DCM and the STO common (SCM) share potential inside the drive,
>    so external +24 on DCM with SCM at 0 V (row 54) is a dead short through the drive.
> 2. **Contactor B tap now fused.** Rows 22/22A/24/24A route both 240 V legs through **KB-FU** (2× GMC-3 in
>    DN-F10MN) at the **tap origin** off the branch fuses — same rationale as the PSU-primary fuses (a 16 AWG tap
>    cannot be protected by the 35 A branch).
> 3. **Fuse elements pinned (per BOM):** branch = 3× **JKS-35** (Class J) in US6J1 blocks · 24V-FU = **GMC-5** ·
>    SR-FU = **GMC-3** (spec was 2 A) · PSU-FU = 2× **GMC-3** · KB-FU = 2× **GMC-3**. Blocks used: 6 of 10 DN-F10MN.
> 4. **Enclosure stirring fan added** (rows 97–98) — internal circulation only, no enclosure penetration; NEMA 12
>    rating unaffected. Mount the DB resistor high in the enclosure (short heat path to the lid).
> 5. Feed-lever prox per BOM is the **Carlo Gavazzi ICF12** (PNP-NO, SIO mode) — wiring, colors, and logic sense
>    identical to the P&F unit named in Rev H; rows 73–75 unchanged.

## Conventions & assumptions
- **Type:** all **stranded** (Str), MTW/THHN 600 V 90 °C — NFPA 79 practice for machine tools.
- **Colors (per doc §9):** **BLK** = line/motor power (208/240 V, disconnect-controlled) · **BLU** = 24 VDC control · **GN/YE** = protective earth (PE). E-stop wires 41–44 are the factory M12 cordset colors (BN/WH/BU/BK).
- **Gauge:** power/motor **12 AWG**; 240 V coil & PSU primary **16 AWG**; 24 VDC control **18 AWG**; PE **12 AWG** (power) / **14 AWG** (small bonds).
- **Runs to the machine** are tagged **(mach)** — home-run to the panel, no field j-boxes. Everything else is in-panel or on the panel door.
- **Terminal designations are typical** — verify against each device's own diagram (MSR127 S-terminals, GS20 STO/DI/DCM, CWBS12 mirror aux).
- Tags: JB rear j-box · DISC disconnect · FB fuse block · KA Contactor A · KB Contactor B · CRB interposing relay · VFD drive · MOT motor · DBR brake resistor · PSU NDR-240 · SR safety relay · PLC CLICK PLUS · EST e-stop · RST reset · SEL selector · PND pendant · DRM drum · LSB/LST limits · PRX prox · GRN/RED/WHT pilots · **PSU-FU** PSU primary fuse · **KB-FU** Contactor-B tap fuse · **24V-FU/SR-FU** bus/safety fuses · **FAN** stirring fan · **+24 / 0V** DC buses · **GND** ground bus.
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

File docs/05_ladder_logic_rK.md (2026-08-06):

# Powermatic 1200 Retrofit - CLICK PLUS Ladder Logic

Transcribe into the free **CLICK Programming Software**. Symbols:
`─] [─` N.O. · `─]/[─` N.C. · `─]↑[─` leading-edge (press) · `─]↓[─` trailing-edge (release) ·
`─( )─` OUT · `─(S)─` SET · `─(R)─` RST · `[TMR …]` timer.

> **Scan order is load-bearing in Rev K.** The bidirectional stop-first behavior and the jog-mode
> short-press logic depend on rungs executing in the order listed. Two rules to preserve: (a) the DRILL
> **latch-SET** rungs (4, 5) run **before** the **opposite-stop** rung (7); (b) the jog/consume flag `C50`
> is set by the 5 s entry hold before the jog output rung can act on that held FWD input. Transcribe in
> the numbered order and don't reorder.
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

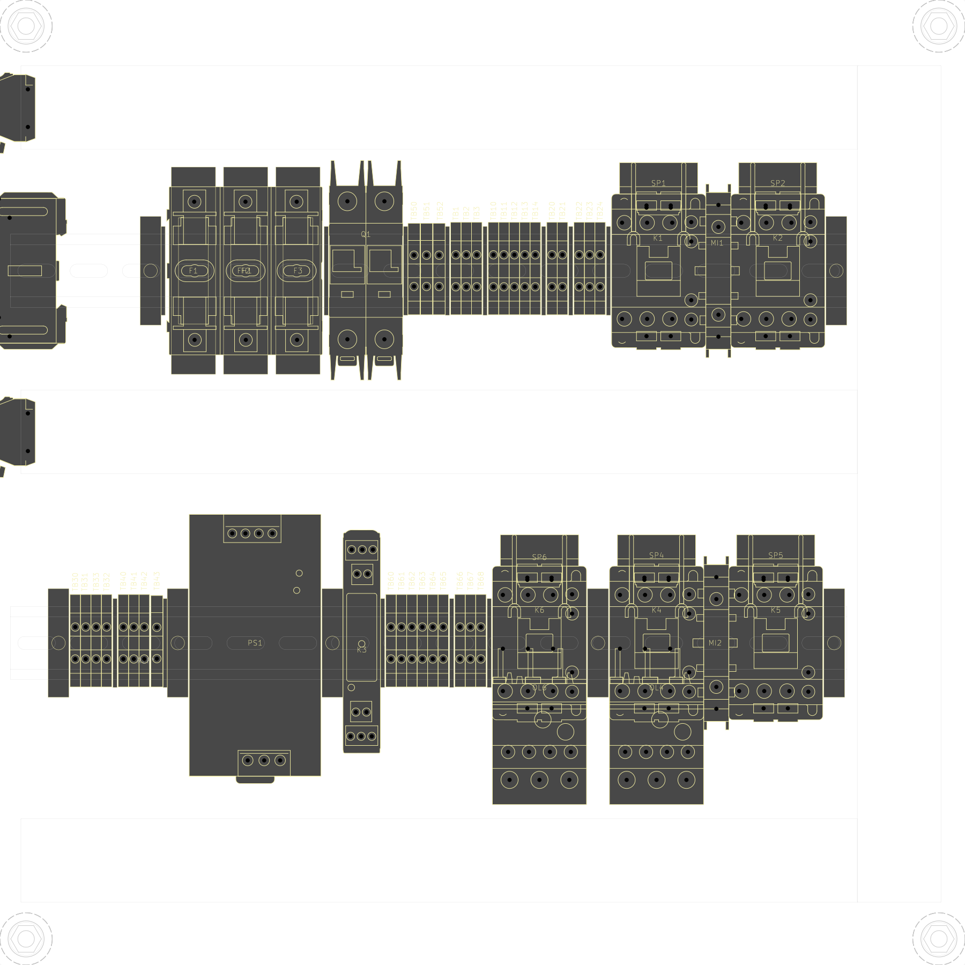
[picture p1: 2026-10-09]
reviews/din_grid_repack/layout.png

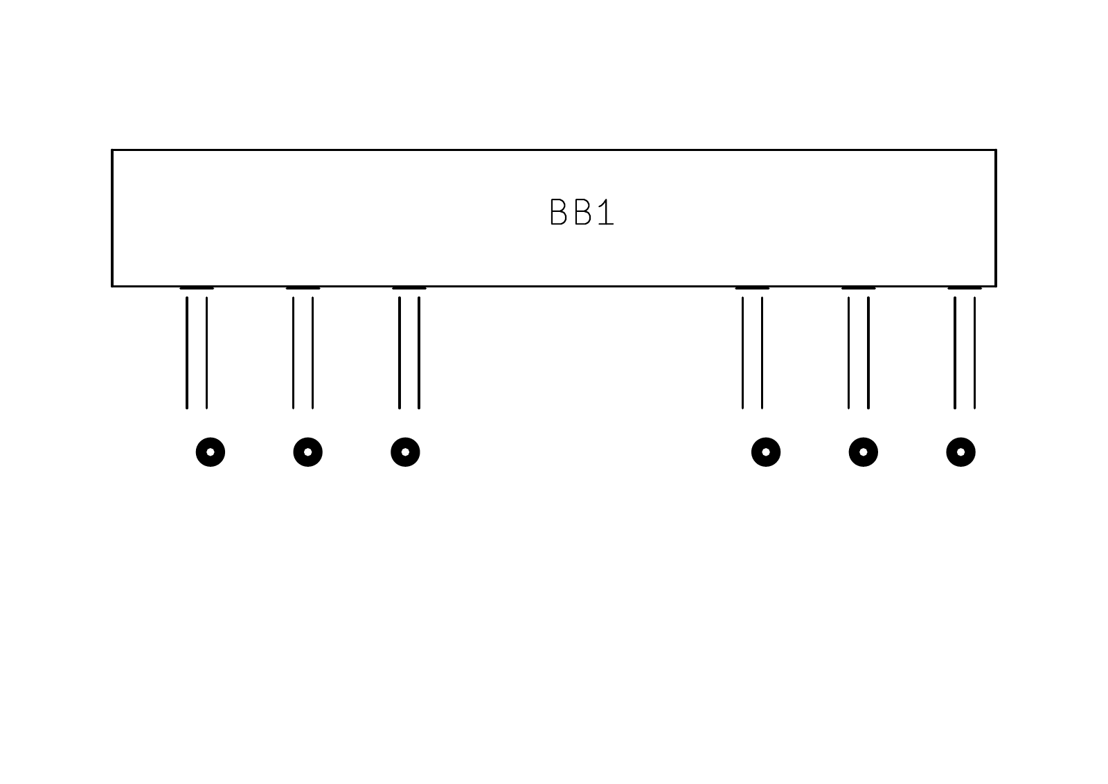
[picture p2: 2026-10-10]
reviews/HMX1-BBREV_split_2026-10-09/TOP.png

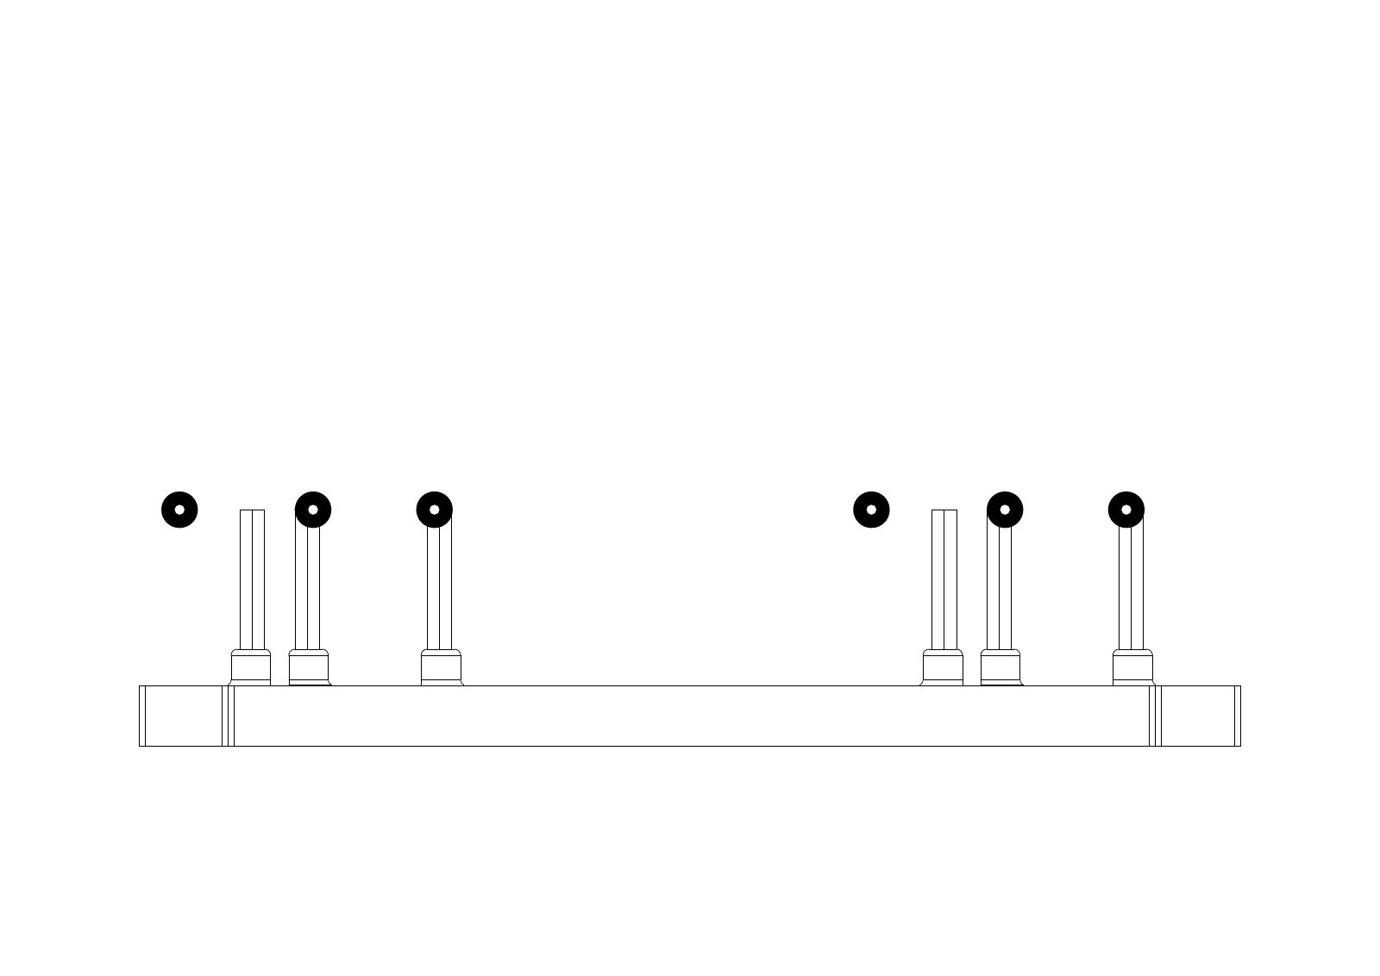
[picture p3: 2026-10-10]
reviews/HMX1-BBREV_controls_2026-10-09/BOT-fab.png

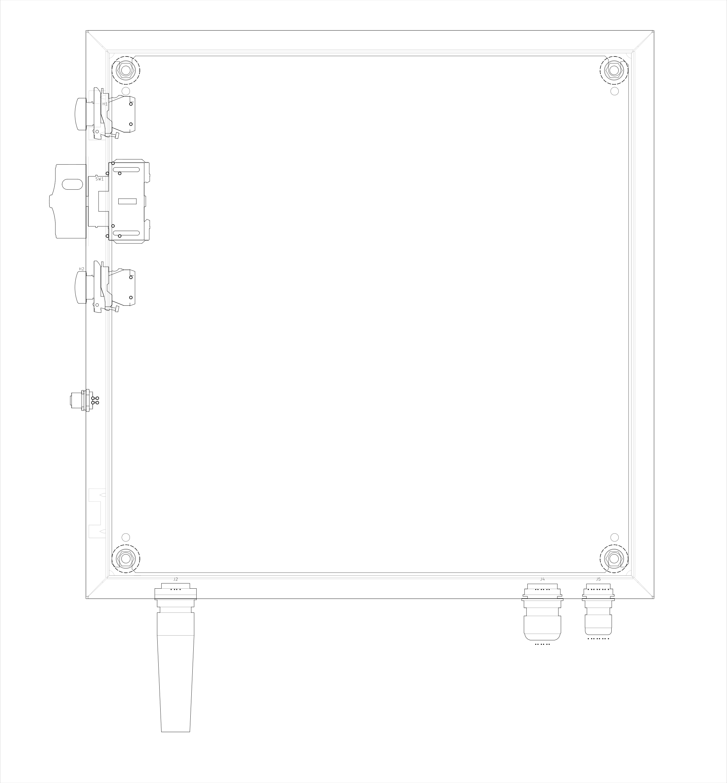
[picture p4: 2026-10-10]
reviews/placement_grid_2026-10-09/layout.png

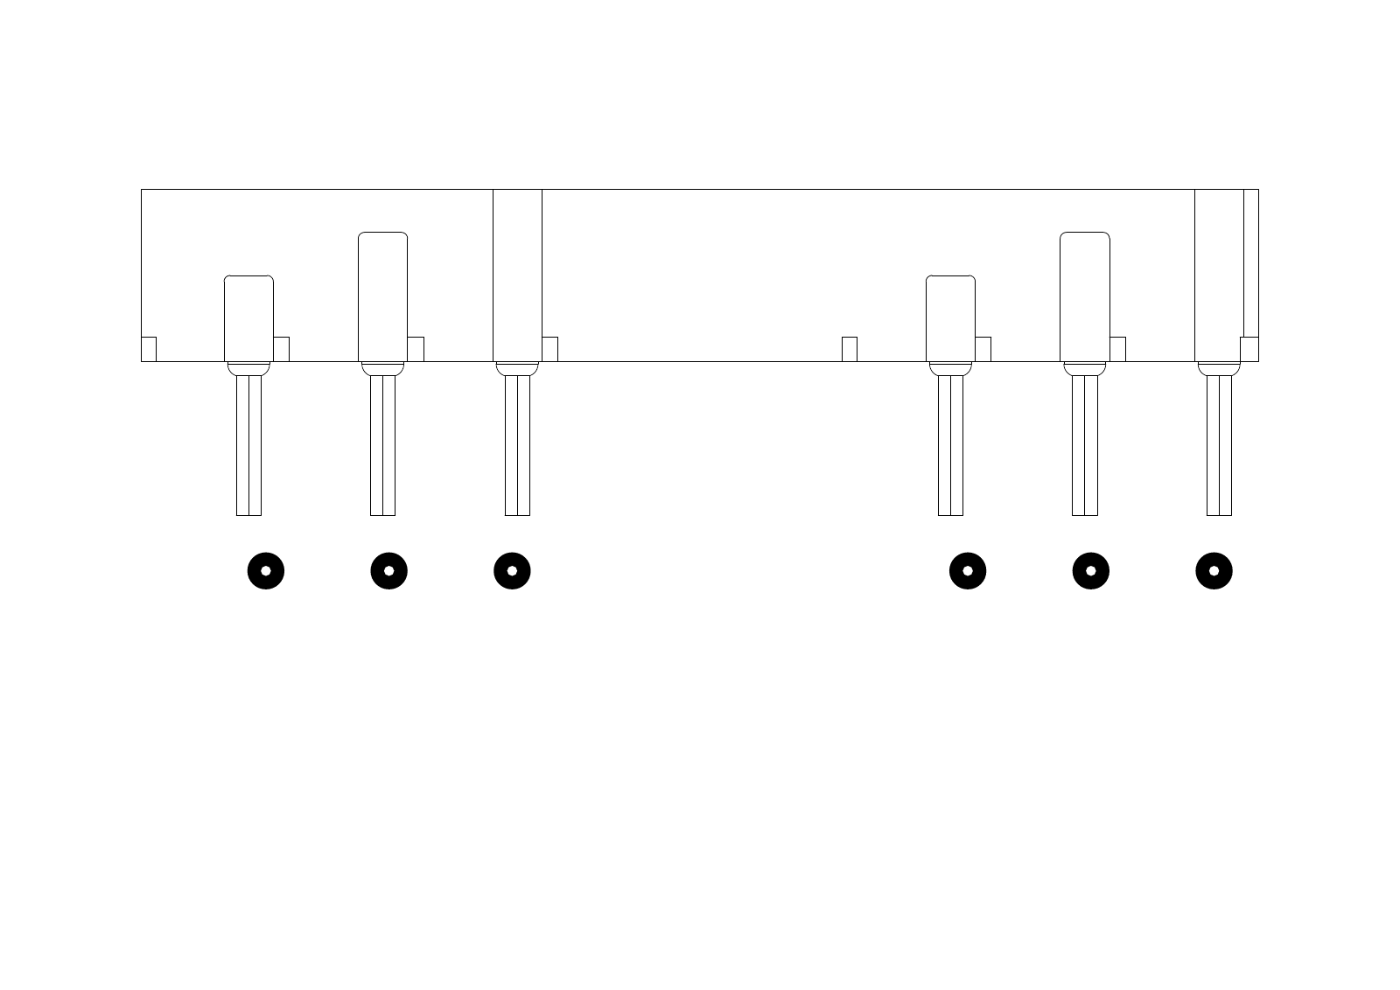
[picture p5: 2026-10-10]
reviews/HMX1-BBREV_controls_2026-10-09/TOP-fab.png

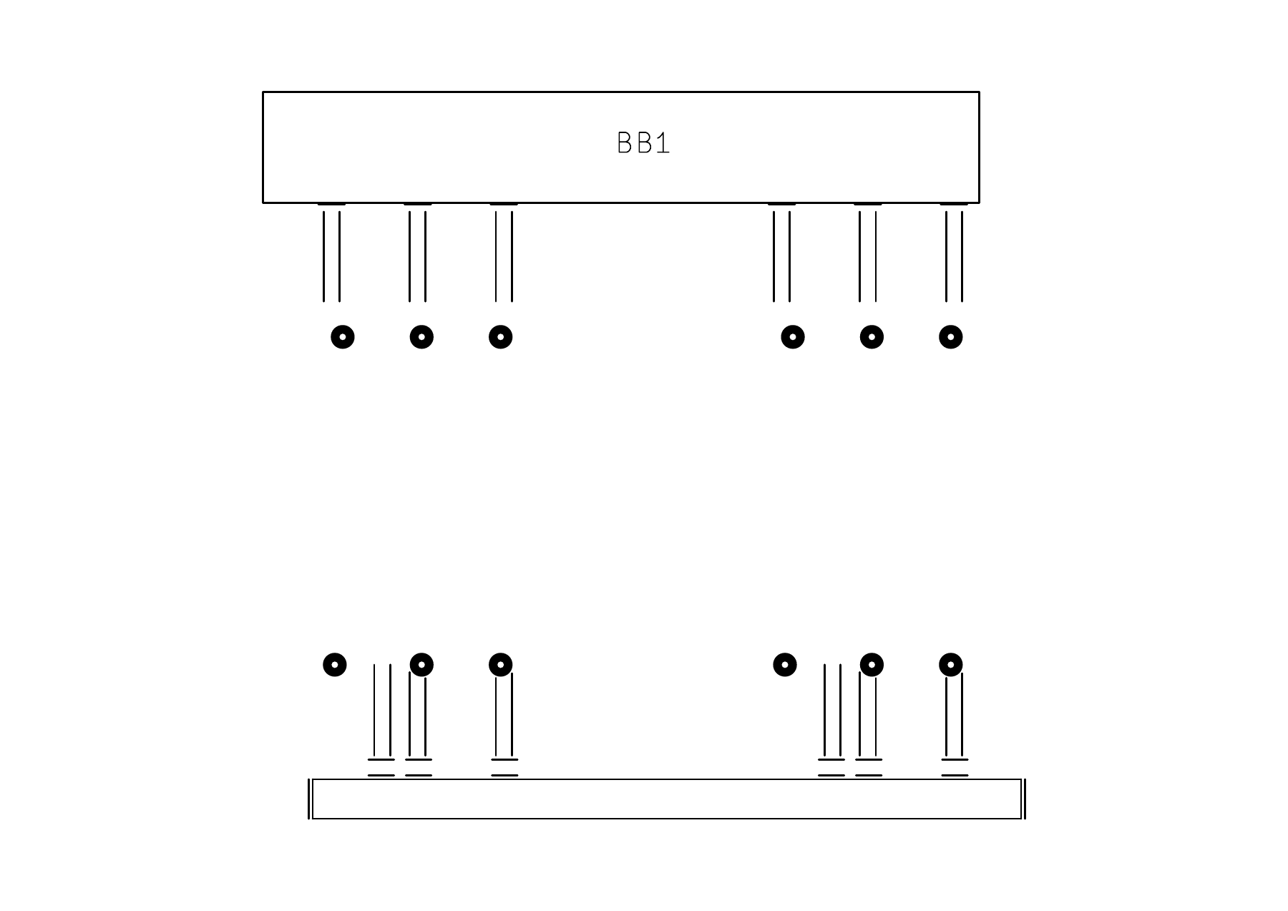
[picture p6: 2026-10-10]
reviews/HMX1-BBREV_2026-10-09/footprint-preview.png

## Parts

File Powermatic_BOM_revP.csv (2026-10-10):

TYPE | NAME | QUA | PACK | UNIT | COST | LINE | SUPPLIER | SPN | SOURCE | SOURCE KEY | KICAD QTY
Contactor | Power Contactor (HMC-9B30-11-DS) | 5 | 1 | EA | 31.00 | 155.00 | AD | HMC-9B30-11-DS | KiCad | part:hmc9b3011ds | 5
Contactor | Contactor Interlock (HMX1-MI) | 2 | 1 | EA | 16.50 | 33.00 | AD | HMX1-MI | KiCad | part:hmx1mi | 2
Contactor | Coil Enable Relay (HC3096N-52-900-24) | 1 | 1 | EA | 46.50 | 46.50 | AD | HC3096N-52-900-24 | KiCad | part:hc3096n5290024 | 1
Contactor | Reversing Busbars (K1/K2) | 1 | 1 | EA | 17.00 | 17.00 | AD | HMX1-BBREV | Local
Power | DC Power Supply (NDR-240-24) | 1 | 1 | EA | 0.00 | 0.00 | GBB | NDR-240-24 | KiCad | part:ndr24024 | 1
Power | Circuit Breaker (FAZ-D4/2-NA-L) | 1 | 1 | EA | 55.00 | 55.00 | AD | FAZ-D4-2-NA-L | KiCad | part:fazd42nal | 1
Power | Motor Disconnect (222102) | 1 | 1 | EA | 0.00 | 0.00 | GBB | 6759K211 | KiCad | part:222102 | 1
Fuse | Class RK5 Fuse | 3 | 1 | EA | 7.74 | 23.22 | AllFuses | FRN-R-10 | KiCad | part:frnr10 | 3
Fuse | Fuse Holder (RM25030-3SR) | 1 | 1 | EA | 54.00 | 54.00 | AD | RM25030-3SR | KiCad | part:rm250303sr | 1
Fuse | Fuse Cover | 3 | 1 | EA | 14.00 | 42.00 | GRAINGER | CVR-RH-25030 | KiCad | part:cvrrh25030 | 3
Operator | Speed Switch (365-TAV2111) | 1 | 1 | EA | 0.00 | 0.00 | GBB | AB_365_TAV2111 | KiCad | part:365tav2111 | 1
Operator | Button Station (50MA3KLE) | 1 | 1 | EA | 0.00 | 0.00 | GBB | FURNAS_50MA3KLE | KiCad | part:50ma3kle | 1
Contactor | Thermal Overload (HTOR32-6-S) | 2 | 1 | EA | 31.50 | 63.00 | AD | HTOR32-6-S | KiCad | part:htor326s | 2
Contactor | Coil Surge Suppressor (HMX1-SSVRC-DC) | 5 | 1 | EA | 12.00 | 60.00 | AD | HMX1-SSVRC-DC | KiCad | part:hmx1ssvrcdc | 5
Operator | White Indicator (XB4BVB1) | 1 | 1 | EA | 0.00 | 0.00 | GBB | DK_4008-XB4BVB1-ND | KiCad | part:xb4bvb1 | 1
Operator | Red Indicator (XB4BVB4) | 1 | 1 | EA |  | 0.00 | DK | 4008-XB4BVB4-ND | KiCad | part:xb4bvb4 | 1
Operator | M12 Panel Socket (T4171310004-001) | 1 | 1 | EA | 0.00 | 0.00 | GBB | DK_A125513-ND | KiCad | part:t4171310004001 | 1
Terminal | Feedthrough Terminal (KN-T12GRY-25) | 2 | 25 | PACK | 9.75 | 19.50 | AD | KN-T12GRY-25 | KiCad | part:knt12gry25 | 29
Terminal | End Cover | 1 | 25 | PACK | 6.75 | 6.75 | AD | KN-ECT6GRY-25 | Local
Terminal | End Bracket | 2 | 10 | PACK | 11.50 | 23.00 | AD | KN-EB7-10 | KiCad | part:kneb710 | 7
Terminal | Jumper 10P | 1 | 5 | PACK | 13.50 | 13.50 | AD | KN-10J12 | Local
Terminal | Adhesive Marker | 1 | 250 | PACK | 13.50 | 13.50 | AD | KN-L5-BLANK-250 | Local
Enclosure | Enclosure | 1 | 1 | EA | 353.00 | 353.00 | AD | EN4SD20208GY | KiCad | part:en4sd20208gy | 1
Enclosure | Backplate | 1 | 1 | EA | 51.00 | 51.00 | AD | EP2020 | Local
Enclosure | Mounting Feet | 1 | 4 | PACK | 0.00 | 0.00 | AD | EZPMFHD | Local
Conduit | Speed / Direction Cable Gland | 1 | 5 | PACK | 7.50 | 7.50 | AD | BSPBX-22-W | KiCad | part:bspbx22w | 1
Conduit | Motor Cable Gland | 1 | 5 | PACK | 11.5 | 11.50 | AD | BSPDX-23-W | KiCad | part:bspdx23w | 1
Power | Cable 12AWG 4C 16.5mm OD | 1 | 10 | FT | 0.00 | 0.00 | GBB | 7081K33 | Local
Power | Plug | 1 | 1 | EA | 0.00 | 0.00 | GBB | 7164K52 | Local
Conduit | 3/4" liquid-tight conduit | 1 | 0 | FT | 0 | 0.00 | - | - | Local
Enclousre | Din-Rail 35x7.5x400mm | 1 | 4 | EA | 11.00 | 11.00 | AD | DN-R35S-400-4 | Local
Conduit | WireDuct 40x80x1000mm | 2 | 1 | EA | 18.50 | 37.00 | AD | T1-1530G1-1 | KiCad | part:t11530g11 | 4
Hardware | Ferrule 14 AWG | 0 | 0 | PACK | 0.00 | 0.00 | - | - | Local
Hardware | Ferrule 18 AWG | 0 | 0 | PACK | 0.00 | 0.00 | - | - | Local
Wiring | 14 AWG Black | 1 | 0 | FT | 0.00 | 0.00 | - | - | Local
Wiring | 14 AWG Green/Yellow | 1 | 0 | FT | 0.00 | 0.00 | - | - | Local
Terminal | Grounding Terminal (KN-G12SP-10) | 1 | 10 | PACK | 29 | 29.00 | AD | KN-G12SP-10 | KiCad | part:kng12sp10 | 4
Terminal | Separator | 2 | 10 | PACK | 11.00 | 22.00 | AD | KN-ST1BLK | KiCad | part:knst1blk | 12
Terminal | Top Cover | 2 | 25 | PACK | 15.00 | 30.00 | AD | KN-TC-1S | Local
Operator | E-Stop Assembly | 1 | 1 | EA | 0 | 0.00 | GBB | Inventory | Local
Hardware | Ring 16 AWG #8-32 | 0 | 0 | PACK | 0 | 0.00 | - | - | Local
Hardware | Ring 18 AWG #8-32 | 0 | 0 | PACK | 0 | 0.00 | - | - | Local
Enclosure | Enclosure Bonding Kit | 2 | 1 | EA |  | 0.00 |  | GRDKIT01 | Local
Conduit | 3/4" liquid-tight fittings | 1 | 1 | EA | 0 | 0.00 | - | - | Local
Wiring | 12 AWG Green/Yellow | 1 | 0 | FT | 0.00 | 0.00 | - | - | Local
Wiring | 18 AWG Blue | 1 | 0 | FT | 0.00 | 0.00 | - | - | Local
Wiring | 16 AWG Blue | 1 | 0 | FT | 0.00 | 0.00 | - | - | Local
Hardware | Ferrule 12 AWG | 0 | 0 | PACK | 0.00 | 0.00 | - | - | Local
Hardware | Ferrule 16 AWG | 0 | 0 | PACK | 0.00 | 0.00 | - | - | Local
Hardware | Twin Ferrule 2x14 AWG | 0 | 0 | PACK | 0.00 | 0.00 | - | - | Local
Hardware | Twin Ferrule 2x18 AWG | 0 | 0 | PACK | 0.00 | 0.00 | - | - | Local

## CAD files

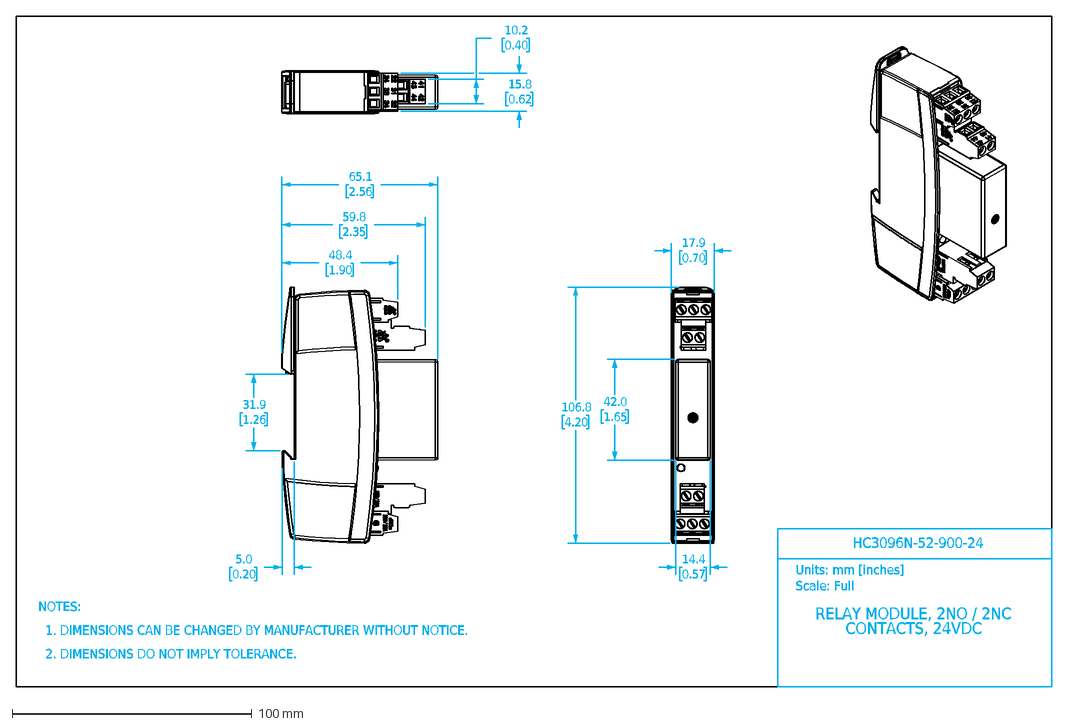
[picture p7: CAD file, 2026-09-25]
HC3096N-52-900-24.dxf
HC3096N-52-900-24
RELAY MODULE, 2NO / 2NC
CONTACTS, 24VDC
Units: mm [inches]
Scale: Full
NOTES:
1. DIMENSIONS CAN BE CHANGED BY MANUFACTURER WITHOUT NOTICE.
2. DIMENSIONS DO NOT IMPLY TOLERANCE.
65.1
2.56
5.0
0.20
31.9
1.26
48.4
1.90
59.8
2.35
17.9
0.70
42.0
1.65
14.4
0.57
106.8
4.20
10.2
0.40
15.8
0.62

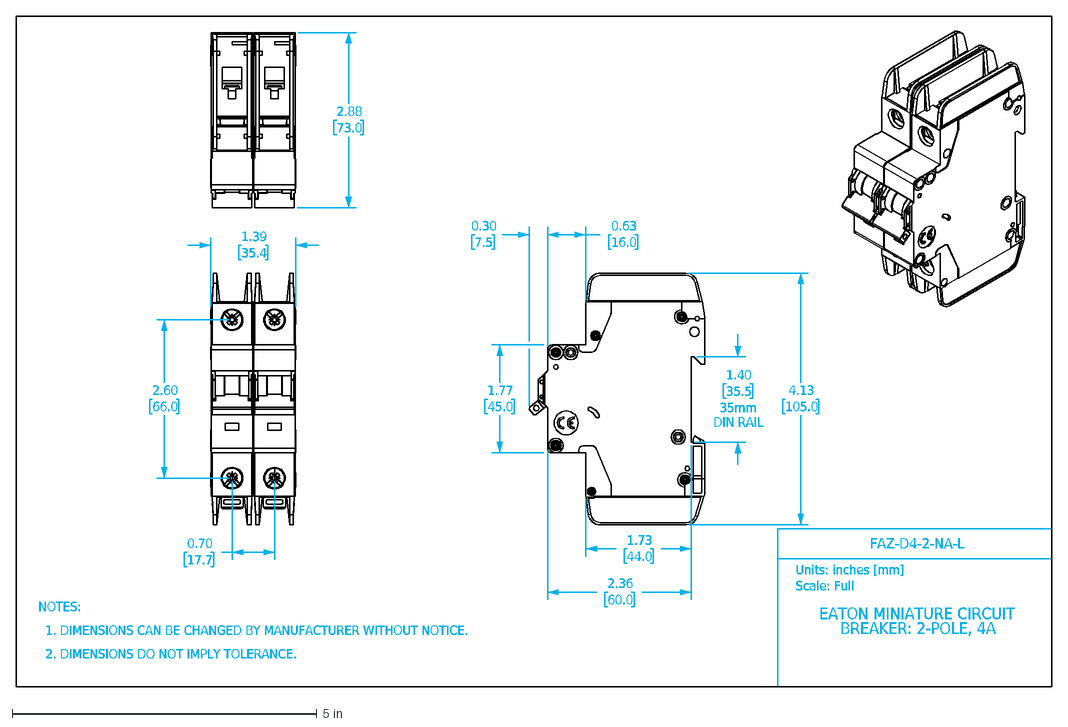
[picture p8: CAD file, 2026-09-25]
FAZ-D4-2-NA-L.dxf
FAZ-D4-2-NA-L
EATON MINIATURE CIRCUIT
BREAKER: 2-POLE, 4A
Units: inches [mm]
Scale: Full
NOTES:
1. DIMENSIONS CAN BE CHANGED BY MANUFACTURER WITHOUT NOTICE.
2. DIMENSIONS DO NOT IMPLY TOLERANCE.
2.60
66.0
0.70
17.7
1.39
35.4
0.63
16.0
1.73
44.0
2.36
60.0
1.77
45.0
4.13
105.0
1.40
35.5
35mm
DIN RAIL
0.30
7.5
2.88
73.0

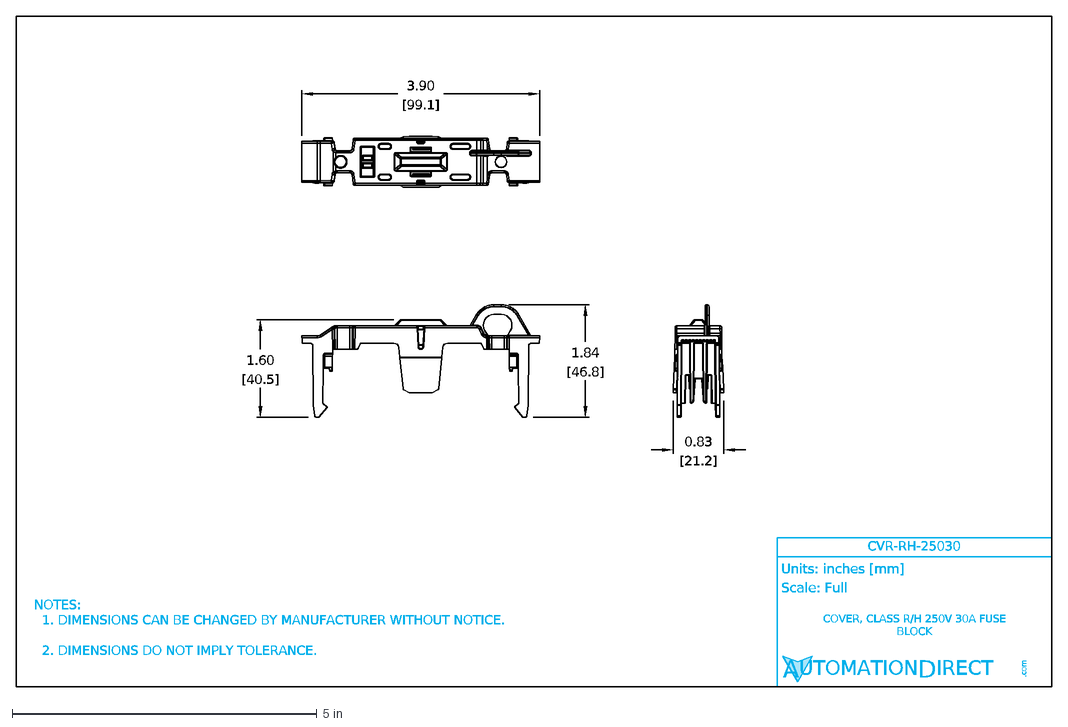
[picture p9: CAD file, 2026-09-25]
CVR-RH-25030.dxf
Units: inches [mm]
Scale: Full
AUTOMATIONDIRECT
.com
CVR-RH-25030
COVER, CLASS R/H 250V 30A FUSE BLOCK
NOTES: 1. DIMENSIONS CAN BE CHANGED BY MANUFACTURER WITHOUT NOTICE. 2. DIMENSIONS DO NOT IMPLY TOLERANCE.
3.90
[99.1]
1.84
[46.8]
1.60
[40.5]
0.83
[21.2]

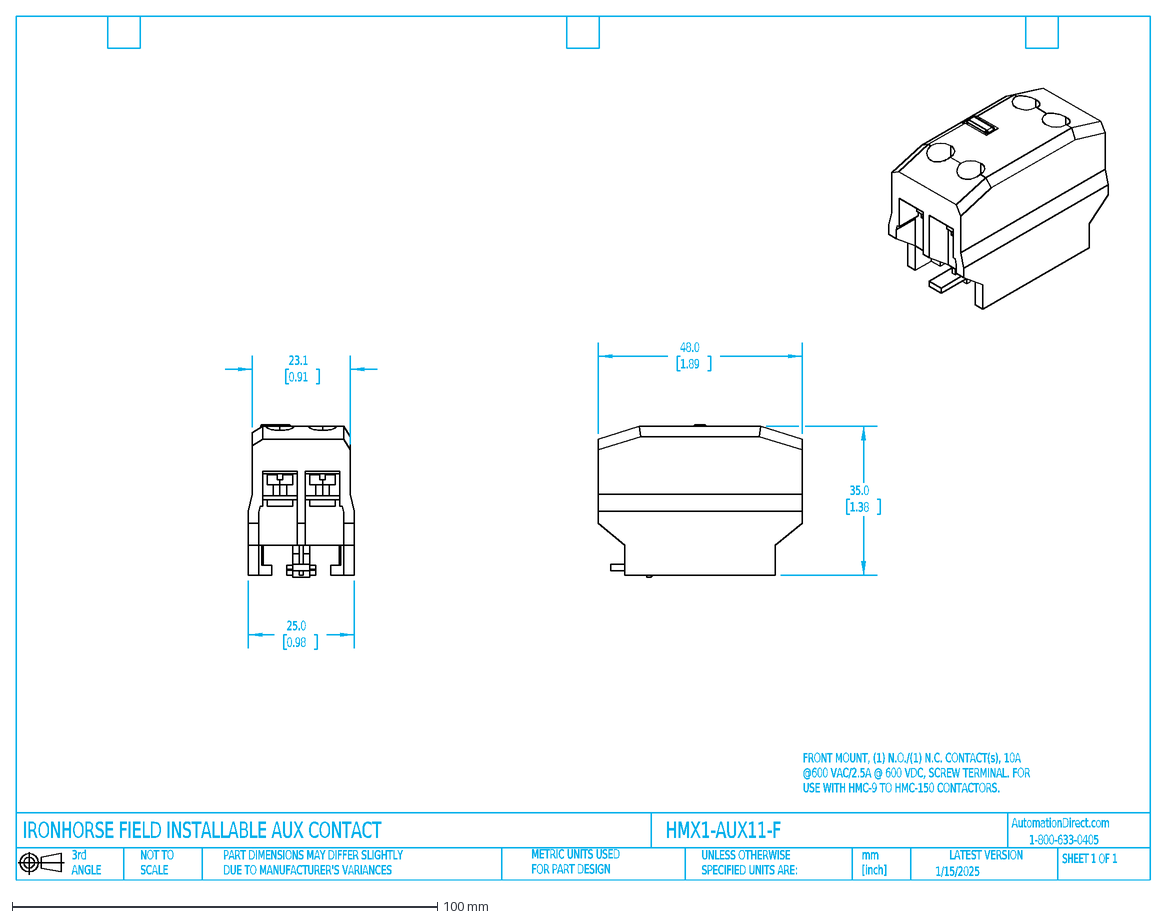
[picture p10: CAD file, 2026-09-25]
HMX1-AUX11-F.dxf
FRONT MOUNT, (1) N.O./(1) N.C. CONTACT(s), 10A @600 VAC/2.5A @ 600 VDC, SCREW TERMINAL. FOR USE WITH HMC-9 TO HMC-150 CONTACTORS.
1/15/2025
IRONHORSE FIELD INSTALLABLE AUX CONTACT
mm [inch]
UNLESS OTHERWISE SPECIFIED UNITS ARE:
LATEST VERSION
PART DIMENSIONS MAY DIFFER SLIGHTLY DUE TO MANUFACTURER'S VARIANCES
NOT TO SCALE
3rd ANGLE
HMX1-AUX11-F
SHEET 1 OF 1
METRIC UNITS USED FOR PART DESIGN
1-800-633-0405
AutomationDirect.com
25.0
0.98
23.1
0.91
48.0
1.89
35.0
1.38

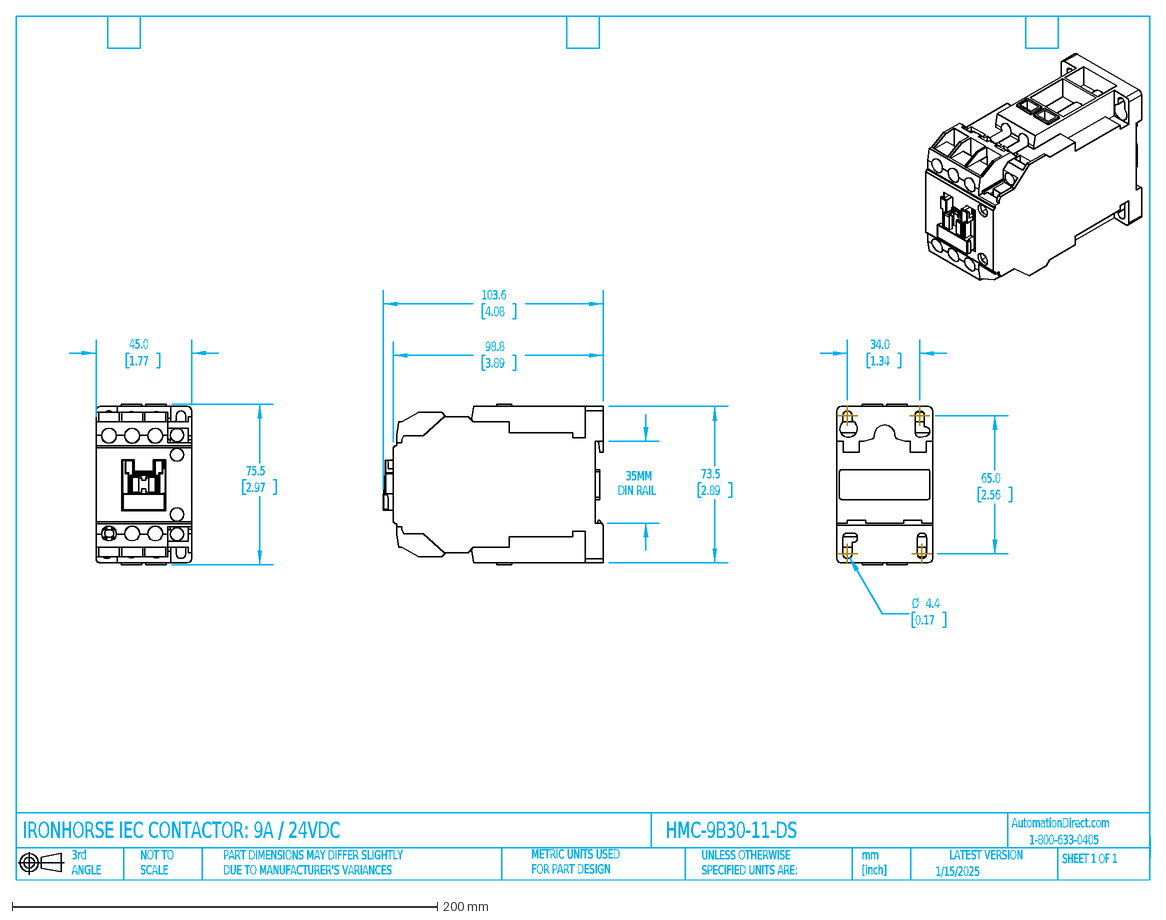
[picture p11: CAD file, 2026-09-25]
HMC-9B30-11-DS.dxf
1/15/2025
IRONHORSE IEC CONTACTOR: 9A / 24VDC
mm [inch]
UNLESS OTHERWISE SPECIFIED UNITS ARE:
LATEST VERSION
PART DIMENSIONS MAY DIFFER SLIGHTLY DUE TO MANUFACTURER'S VARIANCES
NOT TO SCALE
3rd ANGLE
HMC-9B30-11-DS
SHEET 1 OF 1
METRIC UNITS USED FOR PART DESIGN
1-800-633-0405
AutomationDirect.com
75.5
2.97
45.0
1.77
35MM
DIN RAIL
73.5
2.89
98.8
3.89
103.6
4.08
34.0
1.34
65.0
2.56
Ø
4.4
0.17

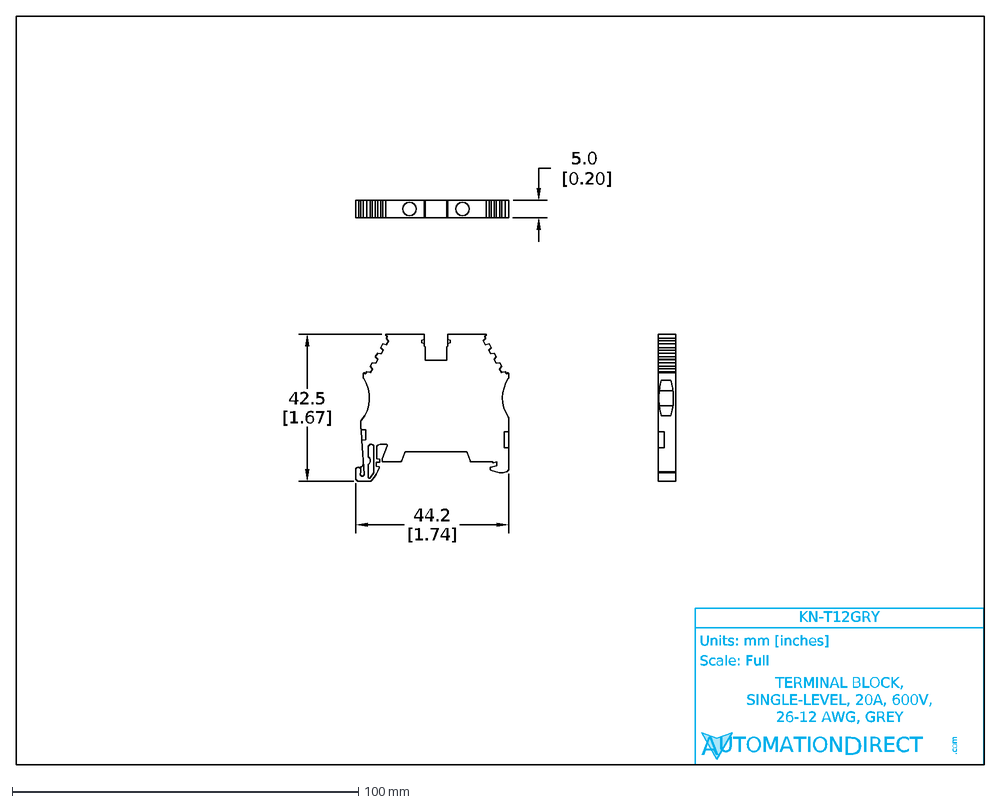
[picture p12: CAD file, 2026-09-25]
KN-T12GRY-25.dxf
Units: mm [inches]
Scale: Full
AUTOMATIONDIRECT
.com
KN-T12GRY
TERMINAL BLOCK, SINGLE-LEVEL, 20A, 600V, 26-12 AWG, GREY
42.5
[1.67]
44.2
[1.74]
5.0 [0.20]

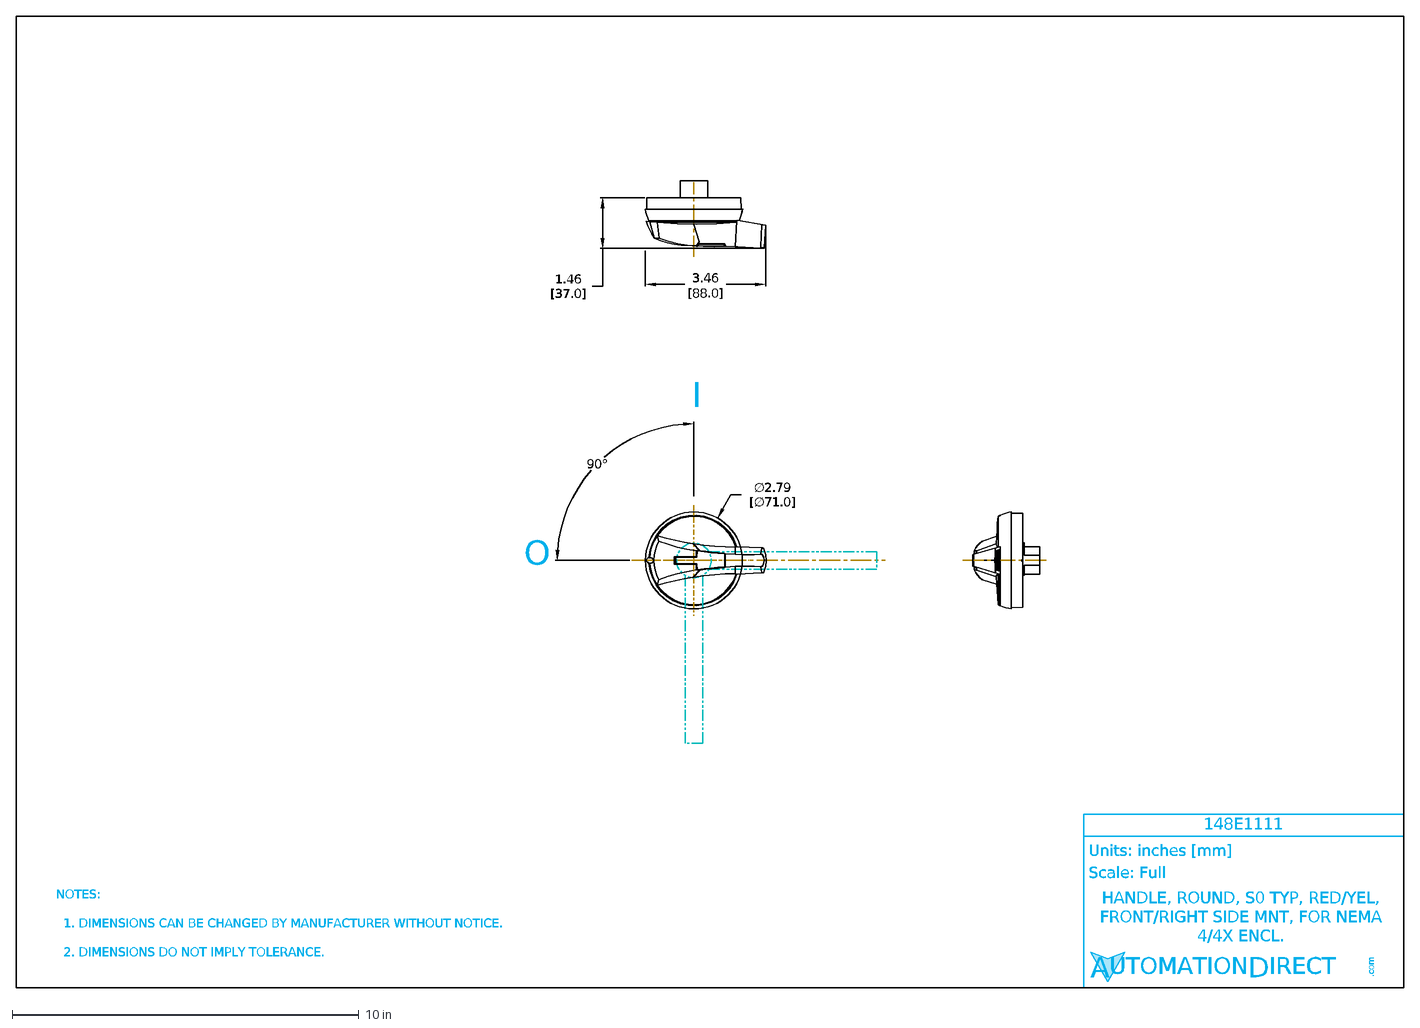
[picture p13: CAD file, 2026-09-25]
148E1111.dxf
Units: inches [mm]
Scale: Full
AUTOMATIONDIRECT
.com
148E1111
HANDLE, ROUND, S0 TYP, RED/YEL, FRONT/RIGHT SIDE MNT, FOR NEMA 4/4X ENCL.
NOTES: 1. DIMENSIONS CAN BE CHANGED BY MANUFACTURER WITHOUT NOTICE. 2. DIMENSIONS DO NOT IMPLY TOLERANCE.
90°
O
I
∅2.79 [∅71.0]
3.46
[88.0]
1.46 [37.0]

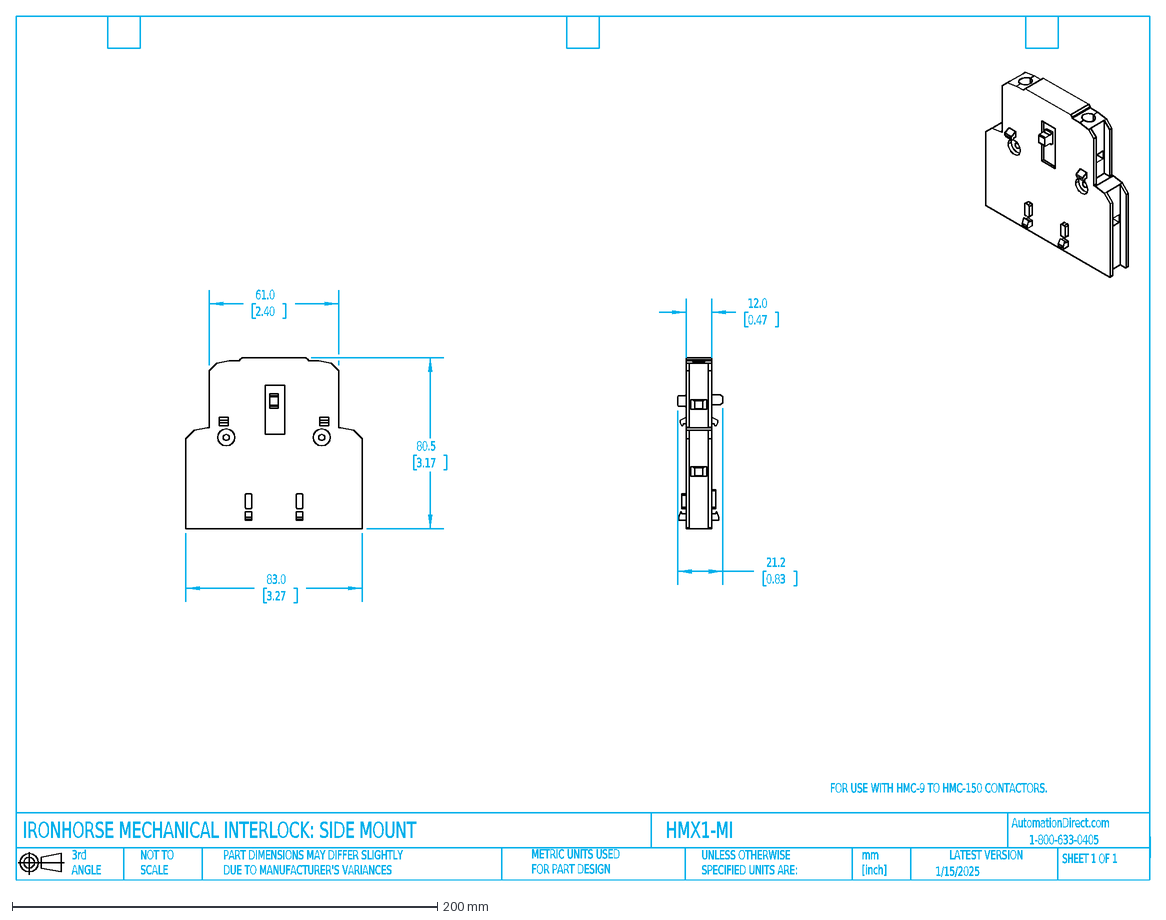
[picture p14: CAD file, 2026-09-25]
HMX1-MI.dxf
FOR USE WITH HMC-9 TO HMC-150 CONTACTORS.
1/15/2025
IRONHORSE MECHANICAL INTERLOCK: SIDE MOUNT
mm [inch]
UNLESS OTHERWISE SPECIFIED UNITS ARE:
LATEST VERSION
PART DIMENSIONS MAY DIFFER SLIGHTLY DUE TO MANUFACTURER'S VARIANCES
NOT TO SCALE
3rd ANGLE
HMX1-MI
SHEET 1 OF 1
METRIC UNITS USED FOR PART DESIGN
1-800-633-0405
AutomationDirect.com
80.5
3.17
83.0
3.27
61.0
2.40
12.0
0.47
21.2
0.83

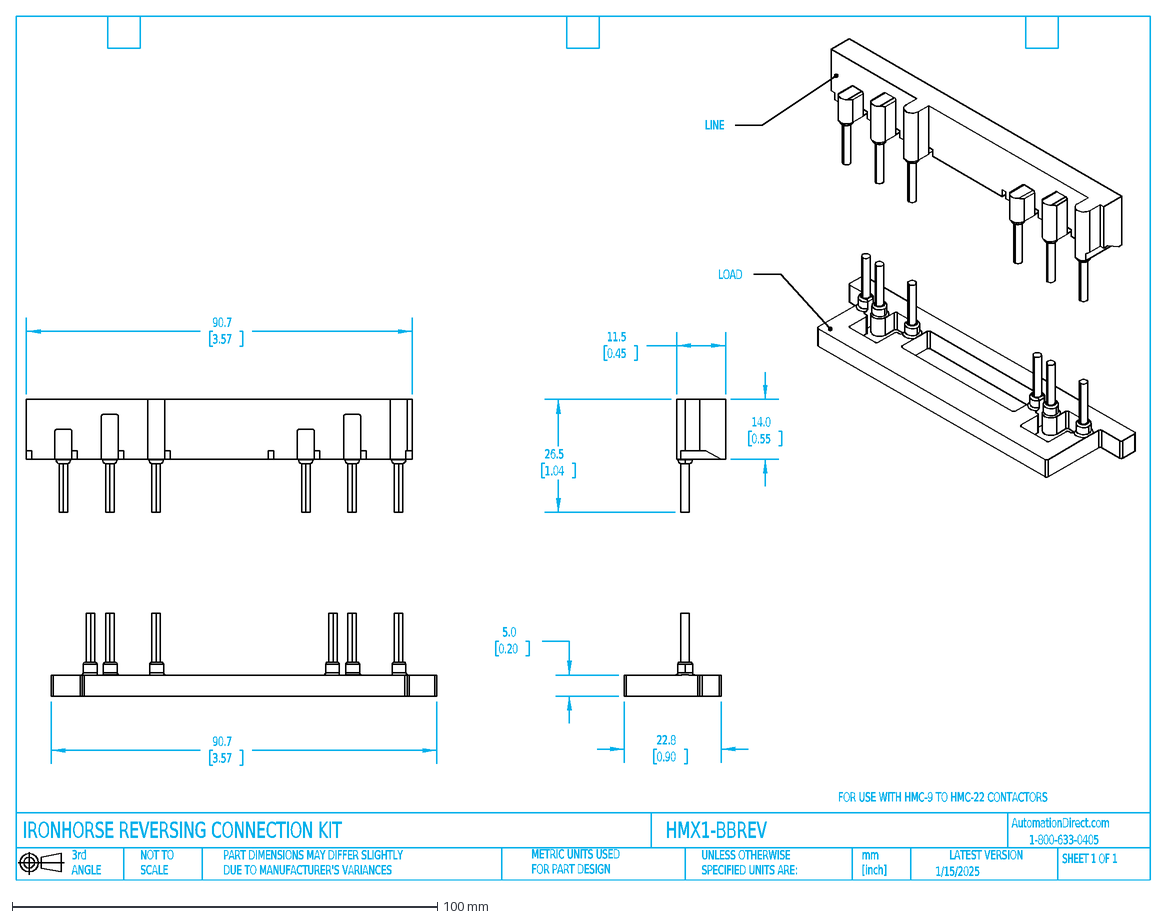
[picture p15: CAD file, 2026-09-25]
HMX1-BBREV.dxf
FOR USE WITH HMC-9 TO HMC-22 CONTACTORS
1/15/2025
IRONHORSE REVERSING CONNECTION KIT
mm [inch]
UNLESS OTHERWISE SPECIFIED UNITS ARE:
LATEST VERSION
PART DIMENSIONS MAY DIFFER SLIGHTLY DUE TO MANUFACTURER'S VARIANCES
NOT TO SCALE
3rd ANGLE
HMX1-BBREV
SHEET 1 OF 1
METRIC UNITS USED FOR PART DESIGN
1-800-633-0405
AutomationDirect.com
90.7
3.57
LINE
LOAD
26.5
1.04
14.0
0.55
5.0
0.20
22.8
0.90
11.5
0.45

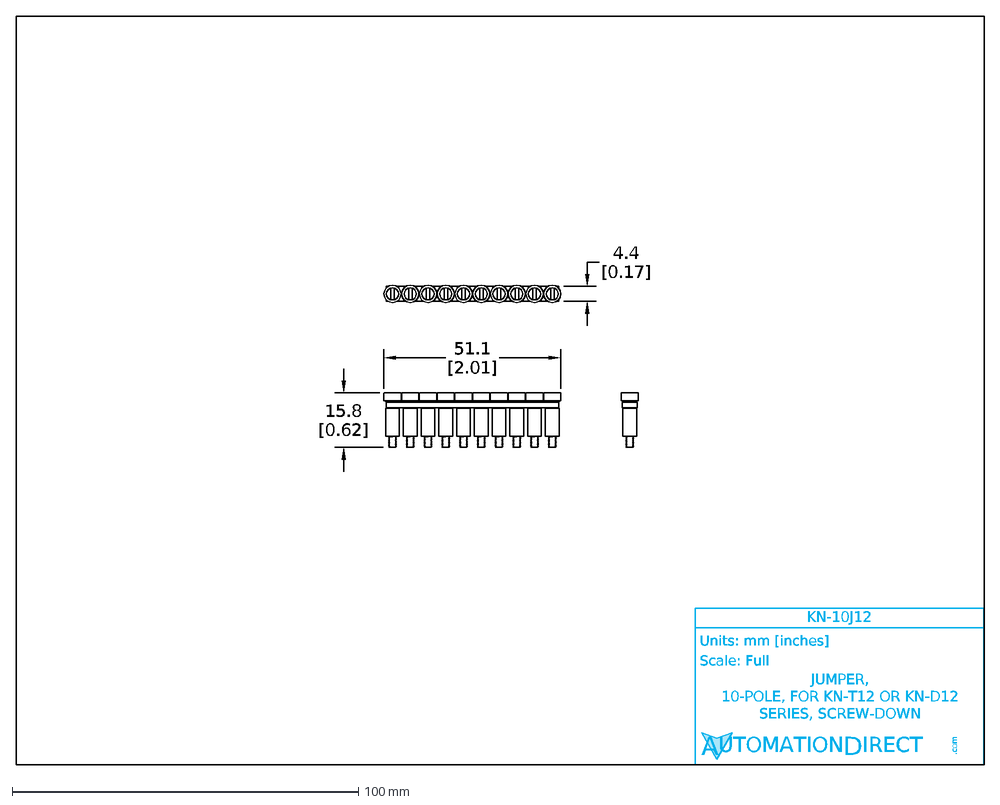
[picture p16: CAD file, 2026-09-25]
KN-10J12.dxf
Units: mm [inches]
Scale: Full
AUTOMATIONDIRECT
.com
KN-10J12
JUMPER, 10-POLE, FOR KN-T12 OR KN-D12 SERIES, SCREW-DOWN
4.4
[0.17]
51.1
[2.01]
15.8
[0.62]

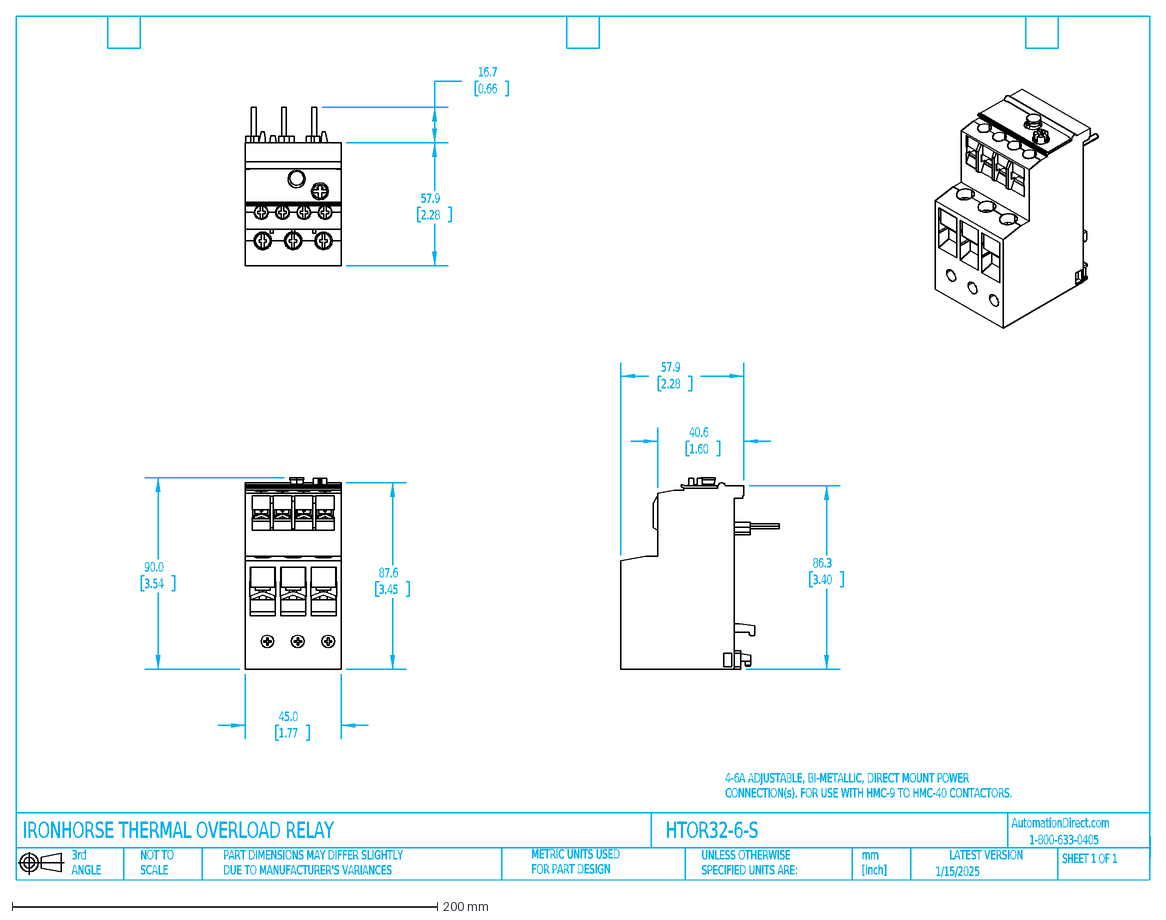
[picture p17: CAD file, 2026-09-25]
HTOR32-6-S.dxf
4-6A ADJUSTABLE, BI-METALLIC, DIRECT MOUNT POWER CONNECTION(s). FOR USE WITH HMC-9 TO HMC-40 CONTACTORS.
1/15/2025
IRONHORSE THERMAL OVERLOAD RELAY
mm [inch]
UNLESS OTHERWISE SPECIFIED UNITS ARE:
LATEST VERSION
PART DIMENSIONS MAY DIFFER SLIGHTLY DUE TO MANUFACTURER'S VARIANCES
NOT TO SCALE
3rd ANGLE
HTOR32-6-S
SHEET 1 OF 1
METRIC UNITS USED FOR PART DESIGN
1-800-633-0405
AutomationDirect.com
87.6
3.45
90.0
3.54
45.0
1.77
57.9
2.28
40.6
1.60
86.3
3.40
16.7
0.66

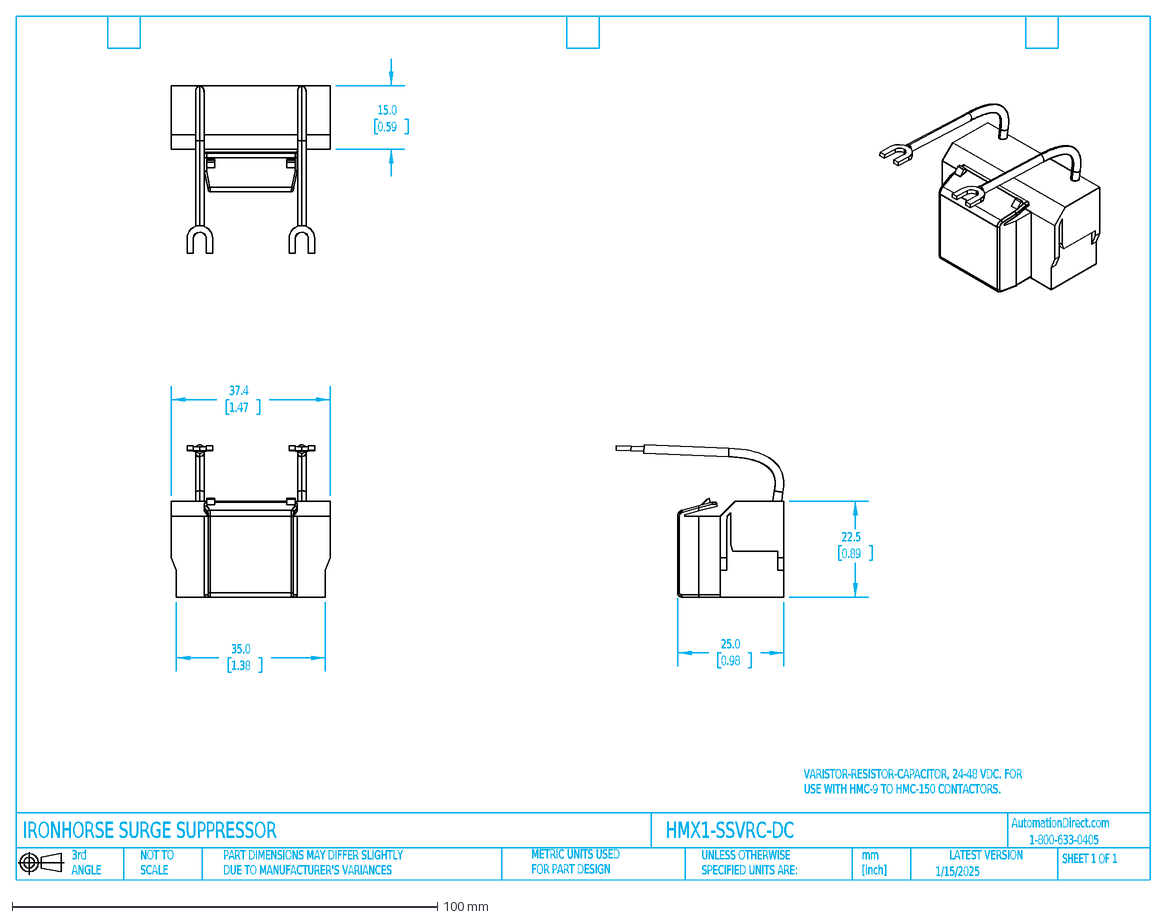
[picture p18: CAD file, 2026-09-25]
HMX1-SSVRC-DC.dxf
VARISTOR-RESISTOR-CAPACITOR, 24-48 VDC. FOR USE WITH HMC-9 TO HMC-150 CONTACTORS.
1/15/2025
IRONHORSE SURGE SUPPRESSOR
mm [inch]
UNLESS OTHERWISE SPECIFIED UNITS ARE:
LATEST VERSION
PART DIMENSIONS MAY DIFFER SLIGHTLY DUE TO MANUFACTURER'S VARIANCES
NOT TO SCALE
3rd ANGLE
HMX1-SSVRC-DC
SHEET 1 OF 1
METRIC UNITS USED FOR PART DESIGN
1-800-633-0405
AutomationDirect.com
37.4
1.47
35.0
1.38
22.5
0.89
25.0
0.98
15.0
0.59

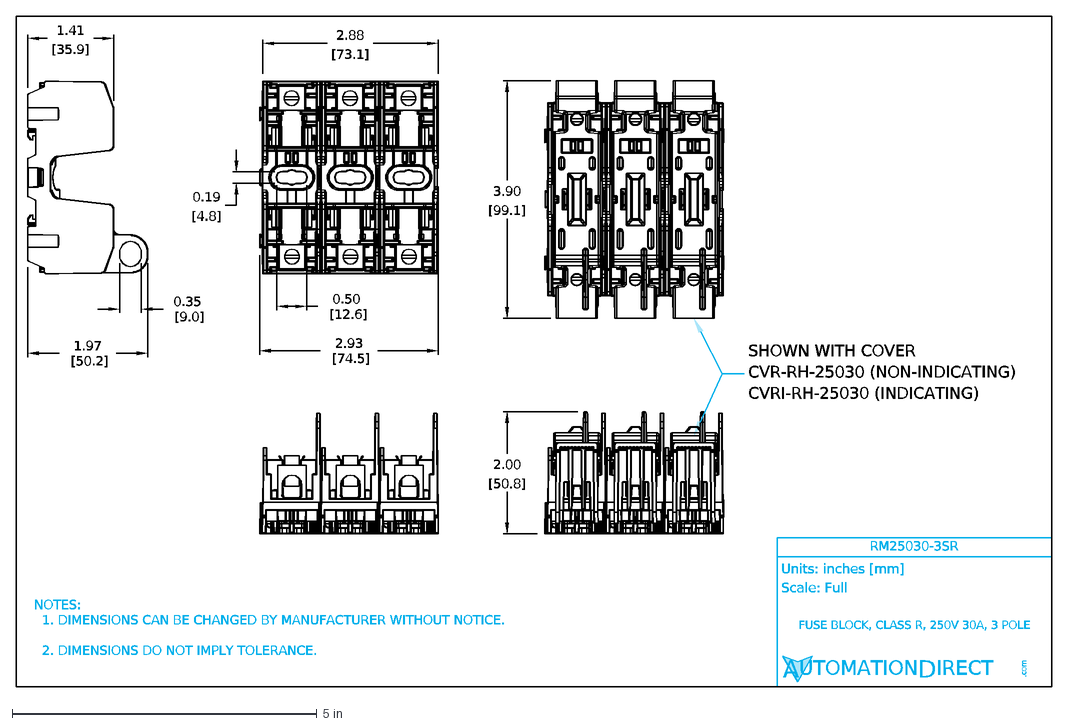
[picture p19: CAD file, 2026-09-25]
RM25030-3SR.dxf
Units: inches [mm]
Scale: Full
AUTOMATIONDIRECT
.com
RM25030-3SR
FUSE BLOCK, CLASS R, 250V 30A, 3 POLE
NOTES: 1. DIMENSIONS CAN BE CHANGED BY MANUFACTURER WITHOUT NOTICE. 2. DIMENSIONS DO NOT IMPLY TOLERANCE.
1.41
[35.9]
1.97 [50.2]
2.00
[50.8]
2.88
[73.1]
2.93 [74.5]
3.90
[99.1]
0.19
[4.8]
0.35 [9.0]
0.50 [12.6]
SHOWN WITH COVER
CVR-RH-25030 (NON-INDICATING)
CVRI-RH-25030 (INDICATING)

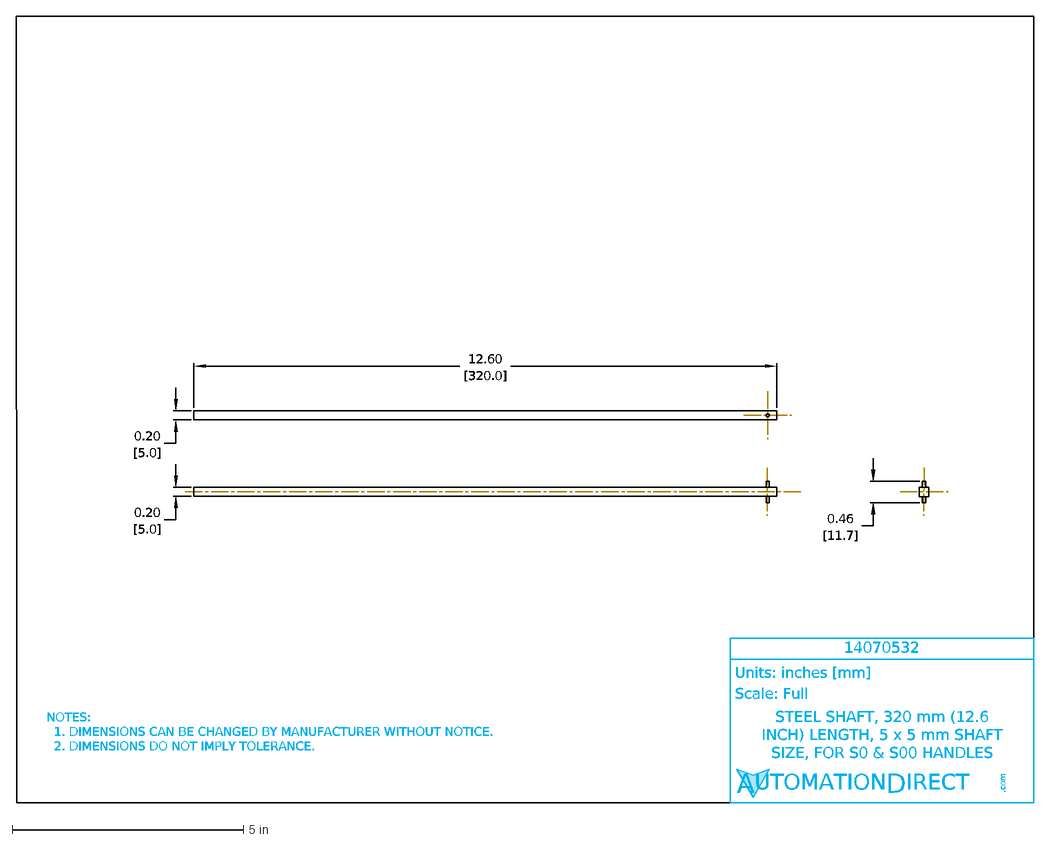
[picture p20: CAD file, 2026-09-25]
14070532.dxf
NOTES: 1. DIMENSIONS CAN BE CHANGED BY MANUFACTURER WITHOUT NOTICE. 2. DIMENSIONS DO NOT IMPLY TOLERANCE.
Units: inches [mm]
Scale: Full
AUTOMATIONDIRECT
.com
14070532
STEEL SHAFT, 320 mm (12.6 INCH) LENGTH, 5 x 5 mm SHAFT SIZE, FOR S0 & S00 HANDLES
12.60
[320.0]
0.20
[5.0]
0.46
[11.7]

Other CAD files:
22943016.dxf
22013003.dxf

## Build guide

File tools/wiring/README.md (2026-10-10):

# KiCad-owned wiring

Saved PCB traces own physical conductor paths. The saved schematic owns logical
connectivity and per-terminal gauge declarations. Placed footprints own
termination selections and can override physical gauge with `Wire.AWG.<pin>`.
The live CSV is an extracted, locally editable schedule.

Use the current names in the [project signal table](../../SIGNAL_NAMING.md).
Net renames must flow through schematic labels, PCB pad/track nets and embedded
`Wire.Sizes` data before extraction. Old `Wire.Wxxx` records are not read by the
trace exporter.

Stale `Wire.Sizes` net stamps are reported and their gauge declarations ignored,
so an edited or flipped symbol does not hide unrelated routed wires. Resolve
the stale declaration to restore its sizing evidence. Nets on the actual routed
endpoints must still agree. Different nets reaching the opposite internally
common clamps of one block are reported as electrical conflicts; all explicitly
drawn wires remain visible, and the extraction review is marked incomplete.

Preferred conductor sizes and component-specific exceptions are defined in the
project [wire-size policy](../../WIRING_STANDARD.md). Actual AWG remains
per-conductor data and terminations belong to the endpoint footprints. The
generator must not substitute a default for a
factory lead or cable-core specification.

## Connection sizes before physical routing

KiCad graphical wires do not have a native AWG property. The custom symbol field
`Wire.Sizes` can hold sizing declarations for every connected terminal while
physical terminal allocation remains pending. Each declaration binds an actual
symbol UUID/pin and native net name to its application and AWG. Different parts
of the same electrical net can have different sizes: 18 AWG panel wiring,
16 AWG external S2/S3 wires and 22 AWG J1 factory pigtails.

The `color` value records black power wire, blue DC control wire and green/yellow
PE wire for discrete conductors. J1 retains its four supplied lead colors.
Incoming cable-core colors are retained as supplied, rather than inferred from
the discrete-wire color convention.

Fixed switch links, suppressor leads, mating connector interfaces and direct-mount
overload connections are classified separately, without guessing a supplied wire
size or adding a loose wire. Internally common coil/PSU terminals do not imply
extra jumpers. `Wire.SizePlan` records planned mechanical PE/bond conductors
without inventing a motor symbol pin.

`sizes.py` prepares a candidate copy and validates declarations against a native
netlist. It never writes the active schematic. Applying a validated candidate
requires saved editors, an editing pause and a source-hash check.

The 2026-10-06 population is installed in the active schematic: all 172 connected
terminals are classified, with 128 numeric AWG assignments and 44 fixed/interface
classifications. M1.PE is 12 AWG, in addition to the six 14 AWG motor conductors.
See the [generated sizing review](../../reviews/wire_sizes_2026-10-06/sizing.md).
Validate the saved sizing fields or refresh their derived review with:

```sh
python3 tools/wiring/sizes.py
python3 tools/wiring/sizes.py --report reviews/wire_sizes_2026-10-06/sizing.md
```

```sh
python3 tools/wiring/sizes.py --stage /private/tmp/powermatic-sizes/powermatic_1200.kicad_sch \
  --report /private/tmp/powermatic-sizes/sizing.md
python3 tools/wiring/sizes.py --schematic /private/tmp/powermatic-sizes/powermatic_1200.kicad_sch
```

Connection-size declarations are not a physical wire schedule. Actual saved
trace paths identify conductors; endpoint metadata supplies their gauges and
terminations. Resolve per-wire sizing conflicts before using a cut list. No
net-wide or copper-width gauge default is inferred.

## Pin termination descriptions

Each physical part footprint has one combined custom field per terminal, named
`Termination.<pin>`: for example `Termination.A1.BOT` or `Termination.P1.A`.
Fields are hidden on F.Fab and editable in Footprint Properties. These are custom
footprint fields keyed by actual pad number, not graphics or a separate summary.
The schedule reads TERM 1 from the source footprint and TERM 2 from the destination
footprint. Missing fields stop export. Wire records do not own termination copies.

The footprint migration moves existing symbol selections into placed footprints
and includes PCB-only terminal blocks. M1, S1 and J6 have metadata-only
footprints: no pads, artwork or models, and excluded from BOM/position exports.
J2 now uses the mains gland model/artwork as its physical routing proxy, with
four pads matching plug terminals X, Y, Z and G. It owns its plug termination
fields and inherits the plug's schematic sizing declarations. The four existing
incoming routes are preserved. `Wire.LengthScope` declares that their cut
estimates cover the panel tail only, excluding the external supply cord.
Enclosure, door and backplate stud descriptions live on the enclosure footprint;
rail lug descriptions live on each rail footprint. Legacy bond descriptions
remain drafts for later topology reconciliation. Feedthrough and ground wire
clamps describe the ferrule/twin-ferrule capability without attaching a wire
gauge to the part. Blocks and unused jumpers are available routing resources
until allocated. Supplied contacts, retained jumpers, cable pass-throughs and
direct-mounted connections are separate from loose-wire crimps. Counts are
terminal fields, not purchasing quantities.

A route terminating at an otherwise uncontinued gland pad is exported as an
explicit drawn section, with the gland's N/A termination and an incomplete
external-length warning. When both paired gland sides are routed, the exporter
joins them into one continuous wire rather than adding a termination at the gland.

Refresh the review from saved fields with:

```sh
python3 tools/wiring/terminations.py --report /private/tmp/footprint_terminations.json
```

`terminations.py --stage-dir <separate directory>` prepares both schematic and
PCB candidates. Existing footprint selections are preserved; conflicting symbol
and footprint choices stop migration. Importing the old CSV is a one-time
migration fallback, not a runtime schedule source. Applying candidates requires
saved editors, an editing pause and source-hash checks. Staging never overwrites
the active files. Preserve these project fields when updating footprints from a
library; actual conductor gauges and selections belong to the placed instances.

Terminal blocks and glands are PCB-only. The saved PCB traces now define the
physical wire graph. Complete pad-to-pad paths become wire rows; unused graphics
and unrouted nets do not. Old W001/W003/W005 schematic records are not used and
their stale UUIDs do not block trace extraction. See the
[trace rules](../schedules/README.md#wiring-ownership) for branches, layers,
glands, gauge selection and cut-length allowances.

Open **Open Wire Schedule Review.app** or **Generate Wiring Review.app**. Both
extract fresh traces into the single existing `Wire_schedule.csv`; Refresh does
the same in the browser. CSV edits remain local. No CSV history is retained.

```sh
python3 tools/wiring/generate.py --open
```

## Route a wire

In PCB Editor, draw a continuous trace between actual terminal pads and save the
PCB. Refresh the wiring browser to add the row. Deleting that saved path removes
the row on Refresh. A path through an intermediate terminal becomes two wires;
branch at a terminal rather than at an unmarked point in space. Set
`Wire.AWG.<pin>` in Footprint Properties when existing endpoint sizing does not
identify the actual conductor. The existing manual-record helpers below are
legacy tools and do not drive the current trace export.

## Add or edit a wire

Use actual KiCad pin numbers in commands. The CSV displays the selected human
labels, such as L1/L2/L3 and TOP/BOT.

```sh
python3 tools/wiring/records.py list
python3 tools/wiring/records.py set W001 --length 500
python3 tools/wiring/records.py set W001 --length auto
python3 tools/wiring/records.py set W001 --review reviewed
python3 tools/wiring/records.py set W002 --from TB40.TOP --to FH1.P1.A
python3 tools/wiring/records.py add W007 --from FH1.P1.B --to SW1.1 \
  --section '02 Fuse outputs and disconnect' --awg 14
python3 tools/wiring/generate.py
```

Save current KiCad edits before changing records through the helper. Reload the
schematic with **File → Revert** after an external record update, before making
more editor changes. The helper refuses to overwrite a file that changed while
it was checking the new record.

Records are hidden `Wire.W001`, `Wire.W002`, etc. properties on each wire's origin
symbol. Each is a JSON object with its origin pin, target symbol UUID and pin,
section, gauge, connection kind, length policy and review state. Termination text
is read from the endpoint footprints' `Termination.<pin>` fields.
Endpoint UUIDs let reference renumbering follow the same physical symbol. Deleting
and replacing a symbol intentionally requires relinking its wire records.
An explicit origin UUID prevents copied symbols from silently duplicating the
original wire list. Inherited records on other copies are ignored and reported.
`WireName` and `WirePin.<number>` fields control output names without changing the
symbol's electrical pin numbers. No extra parts, pins or graphics are introduced.

## Connection kinds

- `wire`: an assembled/installed conductor.
- `panel_cable_core`: an assembled panel tail of an external cable.
- `factory`, `internal`, `bridge`, `plug_cable`: documented fixed connections,
  excluded from assembly rows.

The generator never assumes a complete wire list from a many-pin net. Separate
terminal-block bridges must be recorded. Only the known feedthrough/PE blocks'
internal pin connections are implicit. Factory straps and plug-in M12 conductors
are not inferred as new assembly wires.

## Routing and validation

The board's horizontal ducts are split into top/bottom halves. Vertical ducts
are not split. Device TOP/BOT ports use the duct immediately above/below their
device. Sidewall and gland endpoints use the closest open duct end. Same-whole-
duct paths use the target half's centerline; different whole ducts use whole
centerlines and the vertical trunk. This version supports one vertical trunk.

Current trace endpoints must resolve to real footprint terminals and agree
with the saved schematic's electrical nets. The manual-record validation below
applies only to the legacy helpers.

Every legacy record must resolve to real schematic pins on the same connected net.
Directly drawn wire paths are also checked for the wrong physical terminal clamp,
even when TOP/BOT are electrically common. Missing PCB pads, deleted symbols,
duplicate records and inconsistent routing endpoints stop generation. Conflicting
unrecorded sections are not silently filled in from legacy data or caption text.

Output: root `Wire_schedule.csv`, the single live eight-column schedule.
No extra generated CSV or archived CSV is created. Coverage/provenance are
returned to the caller for status reporting rather than kept as schedule copies.

The exporter checks saved file hashes so a concurrent save cannot publish a mixed
schematic/PCB snapshot. `--check` validates without writing; `--section` filters a
single recorded section. Estimated wire lengths remain estimates for review.

Unannotated symbols in other unfinished sections receive temporary references only
in the export snapshot. Their drawing and saved names are preserved. Generation
stops if an unfinished symbol shares a recorded wire net; other unfinished sections
are listed in the coverage report without blocking the current section.

## Checks

```sh
python3 -m unittest discover -s tools/wiring -p 'test_*.py'
python3 tools/wiring/generate.py --check
```
# Supplied busbar contacts

The HMX1-BBREV_TOP and HMX1-BBREV_BOT footprints each use three native KiCad
`jumper_pad_groups`, for six isolated bridges in total. `Wire.SuppliedAssembly=busbar` marks its contacts as supplier hardware.
`Wire.MatingPads` contains a schema-1 map from each accessory pad to a host role
and terminal number; `Wire.Host.A` and `Wire.Host.B` bind those roles to the
placed host footprint UUIDs. Host roles are independent of reference renaming.

Extraction validates every overlap, host identity, schematic net, and native
jumper group before collapsing a supplier contact onto its host terminal.
Unexplained overlaps still fail. Native busbar bridges count toward electrical
coverage and are omitted from loose-wire rows and ferrule conductor counts.
External wires retain the host terminal's name and preparation selection.

The TOP/BOT pieces share `Wire.KitID`; `Wire.PurchaseQuantity` assigns the one
kit to TOP (1) and no additional purchase to BOT (0). Their `PartID` values
identify the pieces while both retain manufacturer MPN `HMX1-BBREV`.

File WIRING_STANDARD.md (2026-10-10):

# Wire-size policy — Powermatic 1200

Control signal names are governed by [SIGNAL_NAMING.md](SIGNAL_NAMING.md) and
its linked shared standard. Use the schematic's native net names consistently
in sizing declarations, physical wire records, PCB pad nets and generated outputs.

Preferred gauge set: **12 AWG, 14 AWG, 16 AWG, 18 AWG and 22 AWG**. Use AWG consistently; the previously stated “12GA” means 12 AWG in this project. These are preferred conductor classes, not a requirement to replace factory leads or purchased bonding assemblies with those sizes.

This document is the project policy. Actual conductor gauge and cable/part identity belong in the individual wiring records. Termination selections belong to the endpoint footprints' `Termination.<pin>` fields. A preferred gauge does not by itself establish ampacity, fault protection or terminal suitability.

## Preferred applications

| Gauge | Project application | Current evidence / qualification |
|---|---|---|
| 12 AWG | Incoming mains cable phase and PE cores; discrete motor-conduit PE conductor | Selected McMaster 7081K33 is 12/4 SOOW. Owner specifies one 12 AWG PE conductor alongside T1–T6 in the motor conduit. KN-G12SP-10 includes 12 AWG in its wire range; conductor preparation and termination selection still apply. Existing incoming-phase schematic records specify 12 AWG, although their old terminal endpoints require reconciliation. |
| 14 AWG | Six motor-conduit conductors T1–T6; discrete panel motor-power and PSU AC-input wiring; default custom panel PE wiring where sizing permits | Owner specifies six motor conductors. Current BOM stocks 14 AWG black machine wire and 14 AWG green/yellow machine wire. Per-circuit protection and actual terminal specifications still govern. |
| 16 AWG | Individual external control wires in conduit: five for S2 and three for S3 | Owner confirms individual wires and selects 16 AWG for both runs. Match circuit protection, wire product and terminations to the installed conductors. |
| 18 AWG | New discrete 24 V control wiring inside the enclosure/operator stations, including coil/interlock/indicator circuits | Legacy control wiring uses 18 AWG. Match protection to the actual wires and factory leads in each branch before construction. |
| 22 AWG | Small factory connector pigtails, specifically J1's T4171310004-001 M12 leads | The manufacturer drawing specifies 0.34 mm² / 22 AWG. This is a factory-lead class; use 18 AWG as the normal new discrete control-wire choice. Do not infer that all other connector/cable variants have the same leads. |

The preferred classes do not automatically imply a loose-wire spool for every size. The incoming 12 AWG conductors and 22 AWG M12 leads are supplied by the selected cable/device; the motor-conduit 12 AWG PE is a separate discrete wire. Purchase discrete wire only where the physical wire list actually requires it.

## KiCad route widths and netclasses

For panel wire drawings, track width represents the nominal bare conductor
diameter. The presets below use NBS Handbook 100, table 1's nominal diameters
in mils, converted to millimetres and rounded to 0.001 mm. They exclude
insulation and are drawing widths; actual stranded-conductor dimensions remain
part-specific.

| Width profile | Nominal diameter / track width (mm) | Use |
|---|---:|---|
| `AWG_10` | 2.588 | Planned prefabricated bonding assemblies |
| `AWG_12` | 2.052 | Incoming cable cores and motor-conduit PE |
| `AWG_14` | 1.628 | Panel power, motor conductors and normal panel PE |
| `AWG_16` | 1.290 | Individual external S2/S3 control-conduit wires |
| `AWG_18` | 1.024 | Internal panel control wiring |
| `AWG_22` | 0.643 | J1's supplied factory pigtails |

KiCad 10 combines functional netclasses with an AWG width profile. The AWG
classes set only track width; functional groups identify the circuit. Existing
clearance, via and other parameters inherit from `Default`. The saved project
contains exact-name assignment patterns, visible in **Board Setup → Net
Classes**. The Net Inspector groups nets by netclass.

| Functional group | Default width profile | Assigned circuit |
|---|---|---|
| `INCOMING_MAINS` | `AWG_12` | `L1_IN`, `L2_IN`, `L3_IN` |
| `PANEL_POWER` | `AWG_14` | Fused/switched/direction power, PSU AC input and `HS_SHORT` |
| `MOTOR_POWER` | `AWG_14` | `M1_T1`–`M1_T6`; direct-mounted overload interfaces are separately marked internal |
| `CONTROL` | `AWG_18`, or `AWG_22` for the factory-only E-stop contact link | 24 V supply/return and `CONTROL_*` signals |
| `DIRECTION` | `AWG_18` | `DIRECTION_*` signals |
| `SPEED` | `AWG_18` | `SPEED_*` signals; retained S3 straps are separately marked internal |
| `PE` | `AWG_14` | Panel PE default; choose `AWG_12` or `AWG_10` for the specified individual conductors |
| `DEVICE_INTERNAL` | No assumed AWG | Direct-mounted overload interfaces and retained S3 straps; retain the existing `Default` drawing width |

A netclass width is a routing default, not a per-conductor gauge declaration.
The saved declarations contain 13 mixed-gauge nets: incoming phases, PE,
24 V/E-stop circuits and external control signals. Select the actual conductor's
width preset when routing those individual wires. In particular, external
S2/S3 wires use the 1.290 mm preset even though their panel-side net default is
1.024 mm. Use the 0.643 mm preset for J1's supplied leads on mixed E-stop nets.
The existing `Wire.Sizes`, `Wire.AWG.<pin>` and termination fields continue to
own actual conductor specifications; the schedule does not infer AWG from
track width.

PCB Editor is configured for **90 degree rounded** routing with free-angle
mode disabled. New routes use horizontal/vertical straight sections joined by
fillet arcs. The project disables automatic width pickup from an existing
track, so an old 0.2 mm trace cannot silently override the netclass width.
Select **Use netclass width** for the normal default, or an AWG preset for an
individual mixed-gauge wire. These settings preserve existing routed geometry.

The corner setting is a KiCad user preference and applies across projects on
this Mac. KiCad's corner-mode shortcuts can still change it during routing.
Rounded tracks use real arcs; KiCad does not support dragging arcs and treats
them as immovable in shove mode.

Sources: [NBS Handbook 100, Copper Wire Tables, table 1](https://nvlpubs.nist.gov/nistpubs/Legacy/hb/nbshandbook100.pdf),
[KiCad 10 netclasses and interactive routing](https://docs.kicad.org/10.0/en/pcbnew/pcbnew.html).
The saved assignment inventory is in
[`reviews/routing_standards_2026-10-08/assignments.json`](reviews/routing_standards_2026-10-08/assignments.json).

## Discrete wire colors

Carry forward the existing BOM's color convention by application: black for
power wiring, blue for 24 VDC control wiring and green/yellow for PE. Apply that
same convention to the new 12 AWG motor PE and 16 AWG control-conduit wires.

| AWG | Color | Application |
|---|---|---|
| 12 | Green/Yellow | Motor-conduit PE |
| 14 | Black | Panel power, PSU AC input and motor-conduit T1–T6 |
| 14 | Green/Yellow | Discrete panel PE, including PSU PE |
| 16 | Blue | S2/S3 control-conduit wires |
| 18 | Blue | Internal 24 VDC control wires |

These colors are stored with the sizing entries in the schematic's custom
`Wire.Sizes` fields. Incoming cable cores retain their supplied colors; no new
loose-wire stock color is inferred for them. J1's supplied 22 AWG pigtails retain
pin 1 Brown, pin 2 White, pin 3 Blue and pin 4 Black. Jumpers and other retained
or supplied connections remain separate from this discrete wire inventory.

## External conduit runs — owner specification, 2026-10-06

| Run | Conductors | Destination / function |
|---|---|---|
| Motor conduit | Six 14 AWG plus one 12 AWG | One 14 AWG conductor for each of T1–T6; one 12 AWG PE conductor |
| Controls conduit, S2 | Five individual 16 AWG | S2 forward/reverse/stop button station |
| Controls conduit, S3 | Three individual 16 AWG | S3 OFF/LOW/HIGH drum switch |

The controls run contains eight individual 16 AWG control conductors in total. The owner confirms individual wires in conduit and selects 16 AWG for S2/S3. NFPA 79 (2024), §12.6.2 specifies at least 16 AWG for ordinary lighting/control conductors on the machine and in raceways, or 18 AWG where part of a jacketed multiconductor cable assembly. The 18 AWG enclosure/operator-station provision in §12.6.3 does not establish an 18 AWG minimum for the external conduit run. Retain 18 AWG as the internal panel control-wire default.

The motor conduit replaces the previous McMaster 7081K6 16/7 motor-cable plan. The S2/S3 conduit specification supersedes the previous single McMaster 6452T44 18/7 controls-cable plan. Those cable SKUs and their cable glands remain legacy BOM selections pending procurement reconciliation; do not treat them as conduit fittings or assume the old seven-core controls cable covers the eight specified conductors. Conduit type/size, wire product, fittings, installed lengths and exact terminations remain to be selected.

## Button-station terminations — owner specification, 2026-10-06

S2 is the vintage Furnas 50MA3KLE button station. Its physical terminal IDs are
1T/2T and 1B/2B for FWD, 3T/4T and 3B/4B for REV, and 5T/6T for STOP.
T contacts are normally closed; B contacts are normally open. There are no
5B/6B terminals. All
terminals have #8-32 screws and accept a maximum terminal width or ring OD of
9 mm. The five new 16 AWG wire ends use ring terminals sized for #8 studs, with
an OD no greater than 9 mm. This selection is stored in S2's corresponding
footprint `Termination.<pin>` fields.

S3's three new 16 AWG wire ends (1B, 1T and 2T) use the same existing
16 AWG #8-32 ring-terminal selection, assigned by the owner on 2026-10-06.
This selection is stored in S3's corresponding footprint `Termination.<pin>` fields.

## Component-specific exceptions

### K1/K2 reversing busbars — owner selection, 2026-10-09

Use one HMX1-BBREV kit on K1/K2, represented by two PCB-only footprints:
BB1 `HMX1-BBREV_TOP` is the upper/line-side piece; BB2 `HMX1-BBREV_BOT` is the
lower/load-side piece. Each has six contact pads and three native KiCad
`jumper_pad_groups`. TOP joins 1–1, 3–3 and 5–5; BOT joins 2–6, 4–4 and 6–2.
The existing local BOM item remains one kit. TOP owns purchase quantity 1 and
BOT quantity 0; both share `Wire.KitID=HMX1-BBREV_K1_K2` and retain the actual
manufacturer MPN `HMX1-BBREV`. The exact TOP/BOT names are footprint IDs and
`PartID` values, not separately orderable manufacturer part numbers.

Both footprints bind host roles A/B to the K1/K2 footprint UUIDs and record each
mated pad. Extraction checks host identity, exact overlap and net agreement,
then recognizes the native jumper groups without adding loose-wire rows.
Incoming and outgoing loose wires keep their K1/K2 terminal preparation
selections. Unspecified overlapping terminals remain extraction errors. The
front elevations preserve manufacturer geometry and logical routing targets;
installed 3D depth and physical assembly fit have not been verified.

No suitable catalogued IronHorse kit was found for K4/K5. Keep its existing
wiring plan, including the K5 1–3–5 shorting bridge. HMX1-BBREV's reversing
connections do not match that pair. Source: [IronHorse accessory catalog](https://cdn.automationdirect.com/static/specs/ironhorsehmcandhtor.pdf).

H2 is the red Schneider XB4BVB4 E-stop/control-disabled indicator below SW1.
Connect raw `+24V` to K3.31, K3.32 to H2.X1 on
`CONTROL_ESTOP_DISABLED_FB`, and H2.X2 to `0V`. The two new K3 terminal
connections and both H2 terminals use blue 18 AWG panel-control wiring with
ferrule terminations. The existing E-stop connector/conduit wiring is unchanged.
Physical routes and cut lengths remain pending, as for the other panel wires.

### Terminal preparation selections — owner decisions, 2026-10-09

Ferrule `L` means the metal barrel/contact length, not overall ferrule length or
wire stripping length. Strip wire according to the selected ferrule's instructions.

| Component / terminals | Selected preparation |
|---|---|
| Q1 pins 1/3 (`L1_SW`/`L2_SW`) and 2/4 (`L1_PSU`/`L2_PSU`) | Bare stranded copper, 14 AWG; strip per device instructions. Eaton does not recommend ferrules or crimp terminals for FAZ-NA. |
| PS1 `3_BOT` L (`L1_PSU`), `2_BOT` N (`L2_PSU`), `1_BOT` PE | Bare stranded copper, 14 AWG; 5 mm stripping per the NDR installation manual. These are the three AC-input/PE terminals, not three phase inputs. |
| PS1 `1_TOP`/`2_TOP` (−V, `0V`) and `3_TOP`/`4_TOP` (+V, `+24V`) | Bare stranded copper, 18 AWG; 5 mm stripping per the NDR installation manual. |
| H1/H2 X1 and X2 | Single ferrule, 18 AWG, standard 6 mm metal barrel; owner-selected length. |
| KN-T12GRY-25 feedthrough clamps | Single or twin ferrule for the assigned conductor(s); 10 mm metal barrel. |
| KN-G12SP-10 ground clamps | Single ferrule only, one conductor per clamp; 10 mm metal barrel. |
| FH1 `P1.A`/`P1.B`, `P2.A`/`P2.B`, `P3.A`/`P3.B` | Ring terminal, 14 AWG; #10-32 screw; ring tongue OD ≤9 mm to clear the terminal recess. |
| SW1 pins 1-6 | Bare stranded copper, 14 AWG; 12 mm stripping per the disconnect instructions checked by the owner. |

These selections are stored on the saved footprint instances. All seven PS1
terminals use bare stranded copper. Mean Well's NDR manual gives common wire
preparation instructions for input and output; it does not explicitly approve
or prohibit ferrules. The lamp choice records the owner's decision; it does not
claim a completed physical fit check.

FH1 uses the RM25030-3SR screw-terminal version. The AD drawing shows a nominal
12.6 mm terminal-recess width; the selected 9 mm maximum ring OD keeps clearance
within that width. AD/Z+F V70RK004012 is a sourcing candidate: 16–14 AWG,
5 mm hole, 8.6 mm ring tongue width, 23 mm overall length. The catalog dimensions
support lateral fit; screw seating, barrel/wire exit and cover clearance still
require a physical assembly check. This selection replaces all six previous
FH1 ferrule fields. Sources: [FH1 drawing](https://cdn.automationdirect.com/static/drawings/RM25030-3SR.pdf),
[AD ring-terminal dimensions](https://cdn.automationdirect.com/static/specs/dinwiring.pdf),
[Class R block terminal specification](https://cdn.automationdirect.com/static/specs/efusemodblocksr.pdf).

AutomationDirect's Z+F catalog lists standard single/twin barrel lengths of
8, 10 and 12 mm in the applicable wire sizes. The gray 18 AWG versions are
0.75 mm² per conductor; the red versions are 1.0 mm² per conductor. Keep those
capacities distinct when selecting a ferrule for the actual wire. This catalog
availability does not assign a length to the remaining unverified terminals.
The owner-selected 6 mm lamp ferrules require a separate source.

Sources: [FAZ-NA specifications](https://cdn.automationdirect.com/static/specs/eatonfazna.pdf),
[NDR installation manual](https://www.meanwell.com/Upload/PDF/NDR%20DIN%20rail.pdf),
[AD Z+F ferrule catalog](https://cdn.automationdirect.com/static/specs/dinwiring.pdf).

| Actual size | Component / use | Treatment |
|---|---|---|
| 10 AWG | Proposed Hammond GRDKIT01 prefabricated bonding jumpers | Record the supplied assembly and its installed terminations separately. The enclosure–door jumper retains ring lugs at both ends. For each motor-end jumper, remove the Wago-end lug if present and terminate the correctly stripped 10 AWG conductor in a suitable Wago; retain the far-end ring lug for the motor body or machine-frame bond. Two kits supply four 12-inch assemblies, one spare for the three planned bonds, subject to usable length after modification and stud fit. These are not loose-wire stock and cannot terminate in KN-G12SP-10 clamps. |
| Manufacturer-defined | Suppressor leads, retained switch straps and other fixed device wiring | Keep the actual supplied conductor specification. Do not assign an unverified stock gauge or create an extra assembly wire for a factory/internal connection. |

KN-G12SP-10 accepts 26–12 AWG. Use separate suitable clamps for the incoming cable PE, the 12 AWG motor-conduit PE and PSU PE wire. Its two wire clamps and conductive rail foot are electrically common. Prepare each conductor according to the terminal manufacturer's instructions. The 10 AWG bonding-jumper ends use compatible studs or a wire-splicing connector rated for that conductor; they do not enter these KN-G12SP-10 clamps.

The routed PE continuation `TB43_1` to `TB51_2` uses 12 AWG to match the incoming
mains PE core. The PSU PE branch `TB50_1` to `TB52_2` uses 14 AWG to match the
existing PS1 PE feed. These actual-wire assignments are stored in the four
endpoint footprints' `Wire.AWG.<pin>` fields; they do not set a gauge for the
whole PE net or for unused terminal-block clamps. Both ends use single ferrules
with a 10 mm metal barrel (`F12_10mm` or `F14_10mm`).

All feedthrough-terminal and grounding-block wire clamps use ferrules with a
10 mm metal barrel. Feedthrough clamps use a single ferrule for one conductor
or a twin ferrule for two conductors, sized for the actual conductors. Ground
clamps accept one conductor only and use a single ferrule; no twin ferrules.
These owner requirements are stored in each block footprint's
`Wire.TerminationPolicy`. Individual `Termination.<terminal>` fields describe
the part's termination capability and selected barrel length. They do not assign
a conductor gauge or wire count to an available routing resource. Blocks and unused
jumpers are allocated only when needed during physical routing; available clamps
do not constitute missing wiring data. Select ferrule gauge and permitted
single/twin form for the actual assigned conductors during routing. The grounding block's
PE rail contact is a retained conductive foot, not a ferruled wire clamp.

## Bonding plan and conductor classification

- Three prefab bonds: enclosure stud to door stud; motor-end Wago PE splice to motor body; that same splice to machine frame. The owner specifies cutting off the Wago-end jumper connector if present and inserting the correctly stripped conductor into the Wago. Keep the remaining ring lug at the bonded metal part.
- One cable-core PE connection: mains cable PE to the panel PE terminals, supplied within the incoming cable.
- One discrete external PE connection: the 12 AWG motor-conduit conductor between a suitable panel PE termination and the motor-end PE junction.
- One discrete panel PE wire: PSU PE to a panel PE terminal, using the 14 AWG default subject to actual termination/protection requirements.
- Owner's planned mechanical bonds: three conductive fasteners per rail to the backplate; four conductive fasteners from backplate to enclosure. All holes are to be drilled and tapped. Contact preparation, suitable thread engagement and installed bonding verification remain necessary. These connections are recorded as mechanical bonds, not purchased wire lengths.

Use **PE** for protective-earth conductor naming. Document the actual installation and bonding verification separately from this planned topology.

## Motor-end Wago connections

The owner selects WAGO 221-412 for standard two-conductor wire splices, including
the six 14 AWG motor-conduit conductors to the corresponding T1–T6 motor leads.
Each power splice connects only its corresponding conduit conductor and motor
lead, one conductor per port. The 221-412 accepts up to 12 AWG and specifies
11 mm stripping. Prepare these ends as bare copper; retain the actual supplied
motor-lead gauge and check it against the connector's conductor range.

For the motor-box PE junction involving the 10 AWG grounding straps, the owner
selects the three-port WAGO 221-613, rated for conductors up to 10 AWG. It
replaces the initial two-port 221-612 proposal for this junction. WAGO specifies
12–14 mm stripping; the project uses 13 mm bare ends on all three conductors.

The PE splice needs at least three suitable ports, one conductor per port:

1. Motor-conduit PE conductor: 12 AWG.
2. Modified jumper to motor body: 10 AWG if GRDKIT01 is selected.
3. Modified jumper to machine frame: 10 AWG if GRDKIT01 is selected.

The selected PE junction accommodates one 12 AWG conduit PE conductor and two
10 AWG jumper conductors, one per port. The M1 metadata footprint stores the
connector models, seven motor-conduit end preparations and the three-port PE
connection plan. Compact schedule term codes will be `B14_11mm` for the six
power-conductor ends, `B12_13mm` for the PE feed and `B10_13mm` for each modified
strap end. Six 221-412 connectors and one 221-613 are required for this topology.
These are required component counts; purchasing pack quantities remain separate.

The insulated Wago forms a wire-to-wire PE junction; placing it inside a metal motor junction box does not itself bond that box. Account for the box-to-motor-body bond through a verified conductive attachment or an explicit separate bonding connection. Motor-body and frame bonding attachment hardware/locations remain to be defined and verified.

## Wire schedule presentation

The generated CSV and editor use eight positional columns:
`From, Pin, To, Pin, AWG, Length, Term 1, Term 2`. The two `Pin` titles have
separate column positions; they are not dictionary keys. Length is in millimetres.

Pin labels include the reference, followed by an underscore and the terminal
identifier, for example `PS1_PE`, `FH1_P2A`, `TB40_TOP`, `K1_A1_TOP`.
Hidden PCB footprint fields `Wire.PinLabel.<electrical pin number>` supply
aliases for PS1 and FH1. PS1 output aliases are `V1_NEG`, `V2_NEG`, `V1_POS`,
`V2_POS`. Other compound identifiers replace delimiters with underscores.
Electrical pad numbers, schematic connectivity and routing remain unchanged.
Terminal-block device names display as `Terminal 40`, for example, for `TB40`.

Compact termination codes have no underscore between type and wire gauge:

- `F18_10mm`: single ferrule for 18 AWG, 10 mm metal barrel.
- `F2x18_10mm`: twin ferrule for two 18 AWG conductors, 10 mm metal barrel.
- `R18_1032_9mm`: ring for 18 AWG, #10-32 screw, maximum ring tongue width 9 mm.
- `B18_5mm`: bare stranded 18 AWG copper, 5 mm strip length. Omit the final
  segment when no numeric stripping length is assigned.
- `F14_TBDmm` or `FTBD_10mm`: retain unresolved length or conductor gauge visibly.
- `supplier`: a termination already installed by the device/cable supplier.
- Blank: a non-electrical routing marker that receives no termination.

These are generated presentation labels. The saved footprint `Termination.*`
fields retain the full specification, including maximum ring-width limits,
single-conductor restrictions and factory-connection descriptions. A terminal
block's compact ferrule gauge comes from the actual routed wire; its source
capability does not assign a gauge. Refresh regenerates the compact labels.

## Where information belongs

1. **Policy:** this document owns preferred gauge classes, application defaults and explicit exceptions. Root README and tools/wiring/README link here; avoid duplicating a second policy table in the BOM or generator.
2. **KiCad data:** custom schematic `Wire.Sizes` fields record per-terminal conductor sizing and `Wire.SizePlan` retains proposed bonding assemblies. M1.PE records 12 AWG motor-conduit PE. Saved PCB trace paths own physical wire endpoints and route geometry; the old schematic `Wire.Wxxx` fields are no longer the schedule source. One combined `Termination.<pin>` field on each placed footprint owns the termination selection at that terminal. TERM 1 and TERM 2 are read from the source and destination footprints. M1, J2, S1 and J6 use metadata-only footprints without physical geometry, excluded from BOM and position exports. Bonding-strap attachment hardware belongs in the BOM; mechanical bonding points do not carry wire-schedule termination fields. Reports and wire records do not own duplicate termination selections. These fields do not define routes or wire allocation; Completed routed paths generate wire rows; missing gauge assignments and unrouted connections are reported.
3. **Procurement:** `Powermatic_BOM_revP.csv` owns exact cable/device/spool/ferrule/lug/kit selections and purchase quantities. Include AWG and conductor count in cable descriptions and AWG in termination descriptions; retain the exact supplier part number. A preferred gauge without a required wire is not an automatic BOM purchase.
4. **Live schedules:** `Wire_schedule.csv` is the single live physical-wire schedule. Finder launch or browser Refresh extracts completed saved PCB trace paths into it. CSV edits remain local and never update KiCad. No traces are currently saved, so the fresh schedule contains zero routed wires. `Powermatic_BOM_revP.csv` retains SOURCE tags and stable keys so refresh updates KiCad-linked data while preserving Local purchasing rows and fields; KICAD QTY is separate from purchasing QUA. No historical CSV variants are generated.
5. **Part specifications:** `_parts` datasheets and catalog entries own supplied cable/lead sizes, terminal wire ranges and manufacturer-specific termination requirements. Keep project-wide stock policy here rather than embedding it in reusable symbols.

## Current reconciliation items

- J1's factory leads are 22 AWG. Any 18 AWG extension must be routed as a separate conductor with an explicit joining method; it cannot silently change the factory-lead gauge. The live schedule now reports only completed saved trace paths.
- Old schematic incoming-phase wire records target deleted terminal symbols. They are not read by the trace exporter. Route actual physical paths in the PCB and save before refreshing the schedule; missing routing is reported as incomplete. J2 uses a four-pad mains-gland footprint proxy matching X/Y/Z/G. Its existing incoming traces define the panel tail, not the unrecorded external supply cord; footprint `Wire.LengthScope` records this limit. Gland-only boundaries remain explicit drawn sections, with no inferred electrical termination.
- BOM cable descriptions currently emphasize outside diameter but omit AWG/core count. Its motor/controls cable and gland selections require reconciliation with the new conduit plan. Current loose-wire entries cover 14 AWG black and green/yellow and 18 AWG blue; ferrule entries cover 14 and 18 AWG. Add the required 12 AWG motor PE wire, 16 AWG control-conduit wire, conduit fittings and terminations against the eventual wire list. Choose ferrules/lugs for the actual conductor and device terminal; color alone is not a size specification.
- The saved schematic shows no dedicated DC branch overcurrent device after PS1. NDR-240-24 is a 10 A supply with constant-current overload limiting at 105–130% rated output. Reconfirm protection for the 18 AWG control conductors and especially the 22 AWG factory leads; nominal coil current and a 24 V label are not sufficient evidence of fault protection. This policy records intended classes, not final approval of every wire size.
- Exact wire insulation/type, temperature/voltage rating, routing derating and terminal preparation must be verified against the actual product and circuit. The existing BOM's “machine wire” entries alone do not establish all those specifications.

## Sources reviewed 2026-10-06

- Current saved schematic, current `Powermatic_BOM_revP.csv`, and legacy `Wire_schedule.csv`.
- Owner's 2026-10-06 motor/controls conduit conductor counts and gauges.
- [NFPA 79, 2024 edition](https://previewnorm.com/nfpa/NFPA%2079-2024%20PDF.pdf), §§12.6.2–12.6.4 (printed page 79-43); external raceway versus enclosure control-wire provisions.
- [McMaster incoming cable 7081K33, 12/4](https://www.mcmaster.com/products/wire/cable-awg~12-4/).
- Superseded selection: [McMaster motor cable 7081K6, 16/7](https://www.mcmaster.com/products/electrical-cable/cable-awg~16-7/).
- Superseded selection: [McMaster controls cable 6452T44, 18/7](https://www.mcmaster.com/products/wire/cable-awg~18-7/).
- `_parts/datasheets/T4171310004-001_Drawing.pdf`, factory lead specification 0.34 mm² / 22 AWG.
- [Hammond GRDKIT wire assemblies](https://www.hammfg.com/electrical/products/accessories/grdkit).
- [KN-G12SP-10 manufacturer cut sheet](https://cdn.automationdirect.com/static/specs/cutsheet/KN-G12SP-10_cutsheet.pdf).
- [Mean Well NDR-240 specification](https://www.meanwell.com/Upload/PDF/NDR-240/NDR-240-SPEC.PDF).
- [Wago 221-613, three-conductor 10 AWG connector](https://www.wago.com/us/wire-splicing-connectors/compact-splicing-connector/p/221-613).
- [Wago 221-412/413/415 conductor specifications](https://www.wago.com/us/products/electrical-interconnect/splicing-connectors-221).

## Panel-layout alignment grid

This industrial-controls PCB view is an alignment and wiring workspace. Optimize
it for ease of placement and routing on a 1 mm grid. Prefer integer X/Y footprint
origins and wire-target centers; use the outer face of the mounting panel as the
datum for wall-mounted devices. Preserve terminal identity and connectivity when
adapting a footprint's routing representation.

The backplate view is 462 x 462 mm, from (0, 0) to (462, 462). The 508 x 508 mm
enclosure is centered around it with a 23 mm border: its outer corner datums are
(-23, -23), (485, -23), (485, 485), and (-23, 485). Side-wall device origins use
X=-23; bottom-wall gland origins use Y=485. These layout choices do not change
the enclosure's manufacturer dimensions. See the [placement grid review](reviews/placement_grid_2026-10-09/README.md).

## Integer-grid DIN routing views

The placed integer-origin DIN equipment uses shared `Controls:<base>_Grid1mm` variants. The routing-view mounting faces are integer X coordinates and wire-target pads use ceiling-rounded integer X/Y positions. Original footprints, F.Fab and STEP remain nominal hardware references. The drawing-grid view does not change the hardware conductor or termination specification. See the [layout and complete coordinate audit](reviews/din_grid_repack/README.md).

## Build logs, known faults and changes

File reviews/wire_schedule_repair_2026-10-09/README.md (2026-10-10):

# Wire schedule metadata repair

The saved board lacked footprint-owned termination fields on the contactors,
overloads, glands, fuse holder and H2. Without direct-mounted classifications,
the extractor treated coincident K4.2 / OL4.IN1 pads as competing wire terminals
and aborted Refresh, preserving the empty CSV.

After the owner saved and closed the PCB editor, 135 hidden fields were added
to 11 existing footprints. Missing selections were recovered from the Git
checkpoint and the recorded termination migration, with matching current part
identities and terminal inventories. Current schematic Part Name fields were
used where available. Existing fields were retained. No shared library,
extractor, browser code, placement, pad, net, model or trace was changed.

Structured before/after comparison verified that only these new fields differ.
Native extraction passed and the running review server's Refresh endpoint
returned HTTP 200 and overwrote the live Wire_schedule.csv with 17 rows.
The schematic remained byte-identical. Browser capture/control was discontinued
at the owner's request; the final browser display was not inspected.

The routing review remains incomplete: 133 unfinished trace endpoints and
trace-only components were reported. AWG is missing on TB43.1 to TB51.2 and
TB50.1 to TB52.2. The J2 route is a panel tail; external cord length is excluded.
No electrical, ERC/DRC or assembly signoff is implied.

Keep project-specific Termination fields when updating or replacing footprints.
restored_fields.json records the added selections; validation.json records
the current check results. No historical CSV export is retained.

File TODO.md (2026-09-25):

# Open work

Use [Rev P](Powermatic_BOM_revP.csv) and the saved KiCad project for current work.

- Complete the 24 VDC direction-holding, speed-selection, STOP and E-stop schematic using the verified drum-switch and button-station terminal maps in `_parts`.
- Keep KF/KR and KL/KS interlocked; develop the KH/KS high-speed operation and allocate the available auxiliary contacts in the final schematic.
- Include both overload trip contacts and the coil-enable relay in the final control design. Verify stopped behavior after STOP, overload, E-stop clearing and power restoration against the agreed operating behavior.
- Verify the completed power circuit, six motor-lead connections, protection coordination, supply/coil demand, wire sizing and enclosure/motor bonding before construction and commissioning.
- Review STEP axes, mounting datums, dimensions and actual terminal positions; create the Controls layout footprints if KiCad is used for panel layout.
- Place the panel components, rail and duct, then select enclosure/backplate dimensions and determine rail lengths, duct lengths and disconnect shaft length.
- Replace the single provisional feedthrough-terminal quantity with a final terminal and wiring-accessory takeoff after routing the circuit.
- Record procurement and receipt status as parts are ordered.

External L15-20 plug, drum-switch and button-station modeling is deferred. The fuse model is not required. A terminal-marker model remains unavailable in the sourced set.

Previous reports, model acquisition records and superseded design tasks are available in Git history, including archive commit `8ceac95`.

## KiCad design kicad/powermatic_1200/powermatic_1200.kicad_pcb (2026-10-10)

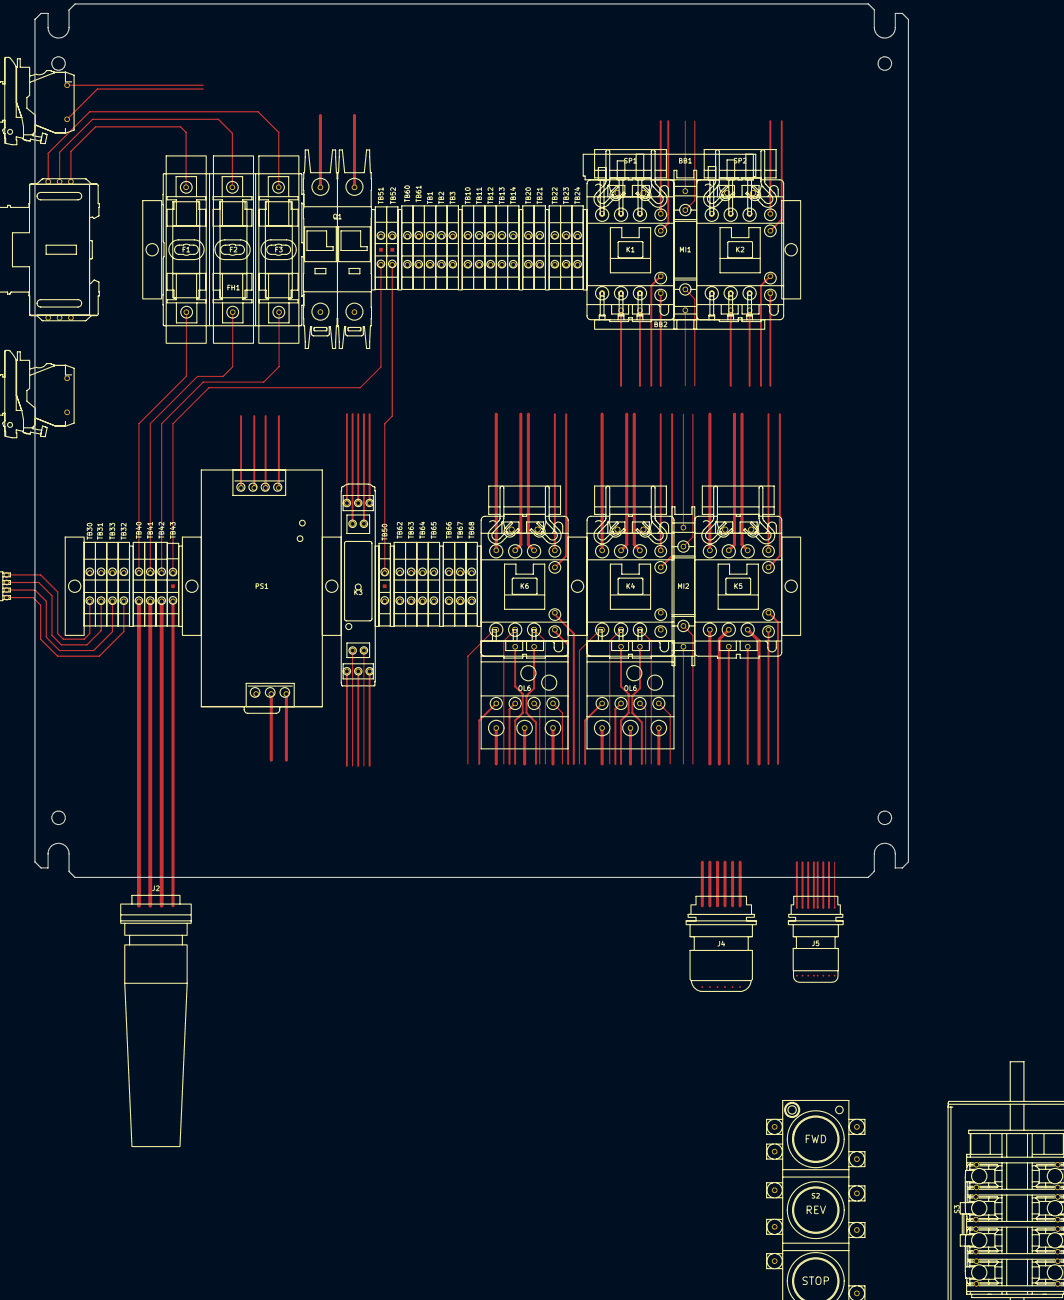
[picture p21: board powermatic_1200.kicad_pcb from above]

Board: 4 copper layers, 462.0 x 462.0 mm, 68 parts (0 on the bottom side), 53 nets.

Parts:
BB1: HMX1-BBREV_TOP
BB2: HMX1-BBREV_BOT
F1, F2, F3: FRN-R-10; FRN-R-10_RM25030-3SR_Front
FH1: RM25030-3SR; RM25030-3SR_Front
H1: XB4BVB1; XB4BVB1_LeftWall
H2: XB4BVB4; XB4BVB4_LeftWall
J1: T4171310004-001; T4171310004-001_LeftWall
J2: 3PH-4W-PLUG; BNSPDX-23-W_MainsPlug_BottomWall
J4: BSPDX-23-W; BSPDX-23-W_BottomWall
J5: BSPBX-22-W; BSPBX-22-W_BottomWall
J6: J6; J6_Termination_Metadata
K1, K2, K4, K5, K6: HMC-9B30-11-DS; HMC-9B30-11-DS_Front_Grid1mm
K3: HC3096N-52-900-24; HC3096N-52-900-24_Front_Grid1mm
M1: PWRM1200-MOTOR; M1_Termination_Metadata
MI1, MI2: HMX1-MI; HMX1-MI_Front_Grid1mm
OL4, OL6: HTOR32-6-S; HTOR32-6-S_Front_Grid1mm
PS1: NDR-240-24; NDR-240-24_Front_Grid1mm
Q1: FAZ-D4/2-NA-L; FAZ-D4-2-NA-L_Front_Grid1mm
S1: PWRM1200-ESTOP; S1_Termination_Metadata
S2: 50MA3KLE; 50MA3KLE_Top
S3: 365-TAV2111; 365-TAV2111_Top
SP1, SP2, SP4, SP5, SP6: HMX1-SSVRC-DC; HMX1-SSVRC-DC_Front_Grid1mm
SW1: 222102; 222102_LeftWall
TB1, TB2, TB3, TB10, TB11, TB12, TB13, TB14, TB20, TB21, TB22, TB23, TB24, TB30, TB31, TB32, TB33, TB40, TB41, TB42, TB60, TB61, TB62, TB63, TB64, TB65, TB66, TB67, TB68: KN-T12GRY-25; KN-T12GRY-25_Front_Grid1mm
TB43, TB50, TB51, TB52: KN-G12SP-10; KN-G12SP-10_Front_Grid1mm

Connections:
0V: H1.X2 (LAMP_2), H2.X2 (LAMP_2), K1.A2.BOT (A2_BOT), K1.A2.TOP (A2_TOP), K2.A2.BOT (A2_BOT), K2.A2.TOP (A2_TOP), K3.A2 (COIL-), K4.A2.BOT (A2_BOT), K4.A2.TOP (A2_TOP), K5.A2.BOT (A2_BOT), K5.A2.TOP (A2_TOP), K6.A2.BOT (A2_BOT), K6.A2.TOP (A2_TOP), PS1.1_TOP (-V1), PS1.2_TOP (-V2), SP1.2 (SUP_2), SP2.2 (SUP_2), SP4.2 (SUP_2), SP5.2 (SUP_2), SP6.2 (SUP_2)
+24V: H1.X1 (LAMP_1), J1.1, K3.13 (NO1), K3.31 (NC1), PS1.3_TOP (+V1), PS1.4_TOP (+V2)
+24V_EN: K3.24 (NO2), OL4.95 (TRIP_NC_1)
/CONTROL_ESTOP_CONTACT_LINK: J1.2, J1.3
/CONTROL_K3_CONTACT_LINK: K3.14 (NO1), K3.23 (NO2)
/DIRECTION_FWD_COIL: K1.A1.BOT (A1_BOT), K1.A1.TOP (A1_TOP), K2.32 (AUX_NC_2), SP1.1 (SUP_1)
/DIRECTION_REV_COIL: K1.32 (AUX_NC_2), K2.A1.BOT (A1_BOT), K2.A1.TOP (A1_TOP), SP2.1 (SUP_1)
/HS_SHORT: K5.1 (L1), K5.3 (L2), K5.5 (L3)
/L1_FUSED: FH1.P3.B (P3B), SW1.1 (L1)
/L1_HIGH: K6.2 (T1), OL6.IN1 (L1)
/L1_LOW: K4.2 (T1), OL4.IN1 (L1)
/L1_PSU: PS1.3_BOT (L), Q1.2 (T1)
/L2_FUSED: FH1.P2.B (P2B), SW1.3 (L2)
/L2_HIGH: K6.4 (T2), OL6.IN2 (L2)
/L2_LOW: K4.4 (T2), OL4.IN2 (L2)
/L2_PSU: PS1.2_BOT (N), Q1.4 (T2)
/L3_FUSED: FH1.P1.B (P1B), SW1.5 (L3)
/L3_HIGH: K6.6 (T3), OL6.IN3 (L3)
/L3_LOW: K4.6 (T3), OL4.IN3 (L3)
/SPEED_HIGH_SHORTING_COIL: K4.32 (AUX_NC_2), K5.43 (AUX_NO_1), K5.A1.BOT (A1_BOT), K5.A1.TOP (A1_TOP), SP5.1 (SUP_1)
/SPEED_LOW_COIL: K4.A1.BOT (A1_BOT), K4.A1.TOP (A1_TOP), K5.32 (AUX_NC_2), SP4.1 (SUP_1)
CONTROL_ESTOP_DISABLED_FB: H2.X1 (LAMP_1), K3.32 (NC1)
CONTROL_ESTOP_ENABLE: J1.4, K3.A1+ (COIL+)
CONTROL_LOW_OVERLOAD_ENABLE: OL4.96 (TRIP_NC_2), OL6.95 (TRIP_NC_1)
CONTROL_OVERLOAD_ENABLE: J5.5.IN, J5.5.OUT, OL6.96 (TRIP_NC_2), S2.1T (FWD_NC_1), S2.3T (REV_NC_1), S2.5T (STOP_NC_1)
CONTROL_RUN_ENABLE: J5.1.IN, J5.1.OUT, K4.43 (AUX_NO_1), K6.43 (AUX_NO_1), S2.6T (STOP_NC_2), S3.1B (LOW1_B), S3.2B (HI2_B)
DIRECTION_ENABLE: J5.2.IN, J5.2.OUT, K1.43 (AUX_NO_1), K2.43 (AUX_NO_1), K4.44 (AUX_NO_2), K6.44 (AUX_NO_2), S2.2B (FWD_NO_2), S2.4B (REV_NO_2)
DIRECTION_FWD_CMD: J5.3.IN, J5.3.OUT, K1.44 (AUX_NO_2), K2.31 (AUX_NC_1), S2.1B (FWD_NO_1)
DIRECTION_REV_CMD: J5.4.IN, J5.4.OUT, K1.31 (AUX_NC_1), K2.44 (AUX_NO_2), S2.3B (REV_NO_1)
L1_DIR: BB2.A2, BB2.B6, K1.2 (T1), K2.6 (T3), K4.1 (L1), K6.1 (L1)
L1_IN: FH1.P3.A (P3A), J2.X (L1)
L1_SW: BB1.A1, BB1.B1, K1.1 (L1), K2.1 (L1), Q1.1 (L1), SW1.2 (T1)
L2_DIR: BB2.A4, BB2.B4, K1.4 (T2), K2.4 (T2), K4.3 (L2), K6.3 (L2)
L2_IN: FH1.P2.A (P2A), J2.Y (L2)
L2_SW: BB1.A3, BB1.B3, K1.3 (L2), K2.3 (L2), Q1.3 (L2), SW1.4 (T2)
L3_DIR: BB2.A6, BB2.B2, K1.6 (T3), K2.2 (T1), K4.5 (L3), K6.5 (L3)
L3_IN: FH1.P1.A (P1A), J2.Z (L3)
L3_SW: BB1.A5, BB1.B5, K1.5 (L3), K2.5 (L3), SW1.6 (T3)
M1_T1: J4.T1.IN, J4.T1.OUT, K5.2 (T1), OL4.2 (T1)
M1_T2: J4.T2.IN, J4.T2.OUT, K5.4 (T2), OL4.4 (T2)
M1_T3: J4.T3.IN, J4.T3.OUT, K5.6 (T3), OL4.6 (T3)
M1_T4: J4.T4.IN, J4.T4.OUT, OL6.2 (T1)
M1_T5: J4.T5.IN, J4.T5.OUT, OL6.4 (T2)
M1_T6: J4.T6.IN, J4.T6.OUT, OL6.6 (T3)
unnamed: S3.3B (HI3_B), S3.4B (LOW4_B), S3.5B (HI5_B)
unnamed: S3.5T (HI5_T), S3.7T (LOW7_T)
unnamed: S3.4T (LOW4_T), S3.6T (HI6_T)
unnamed: S3.7B (LOW7_B), S3.8B (HI8_B)
PE: J2.G (GND), PS1.1_BOT (PE), TB50.1, TB50.2, TB50.PE, TB51.1, TB51.2, TB51.PE, TB52.1, TB52.2, TB52.PE
SPEED_HIGH_CMD: J5.7.IN, J5.7.OUT, K4.31 (AUX_NC_1), S3.2T (HI2_T)
SPEED_HIGH_COIL: K5.44 (AUX_NO_2), K6.A1.BOT (A1_BOT), K6.A1.TOP (A1_TOP), SP6.1 (SUP_1)
SPEED_LOW_CMD: J5.6.IN, J5.6.OUT, K6.31 (AUX_NC_1), S3.1T (LOW1_T), S3.3T (HI3_T)
SPEED_LOW_K6_NC_LINK: K5.31 (AUX_NC_1), K6.32 (AUX_NC_2)

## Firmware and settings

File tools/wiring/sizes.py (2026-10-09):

#!/usr/bin/env python3
"""Validate schematic connection sizes independently of unfinished physical routes.

Wire.Sizes is a custom symbol field. It assigns sizes to terminal connections,
not to KiCad's graphical wire segments or a fabricated conductor graph.
The physical Wire.Wxxx records remain a separate, more detailed data type.
"""
from __future__ import annotations

import argparse
from collections import Counter
import json
from pathlib import Path
import sys
import tempfile

from generate import DEFAULT_SCH
from model import Schematic, change_fields, digest, export_netlist
from source import nodes, one, prop

FIELD = 'Wire.Sizes'
PLAN_FIELD = 'Wire.SizePlan'
SCOPES = {
    'panel_power', 'panel_control', 'panel_pe', 'incoming_cable',
    'motor_conduit', 'controls_conduit', 'factory_pigtail',
    'retained_link', 'suppressor_lead', 'connector_interface',
    'estop_assembly', 'direct_mount',
}
FIXED = {'retained_link', 'suppressor_lead', 'connector_interface',
         'estop_assembly', 'direct_mount'}
WIRE_COLORS = {
    'panel_power': 'Black', 'panel_control': 'Blue', 'panel_pe': 'Green/Yellow',
    'motor_conduit': 'Black', 'controls_conduit': 'Blue',
}
J1_COLORS = {'1': 'Brown', '2': 'White', '3': 'Blue', '4': 'Black'}


def color_for(scope, pin):
    if scope == 'factory_pigtail':
        return J1_COLORS[pin]
    if scope == 'motor_conduit' and pin == 'PE':
        return 'Green/Yellow'
    return WIRE_COLORS.get(scope)


def endpoint_map(schematic, pin_nets):
    result = {}
    for (ref, pin), net in pin_nets.items():
        if net.startswith('unconnected-') or ref.startswith('#'):
            continue
        endpoint = schematic.endpoint(ref, pin)
        result[endpoint['symbol_uuid'], pin] = (ref, net)
    return result


def inspect(text):
    schematic = Schematic(text)
    with tempfile.TemporaryDirectory(prefix='powermatic-wire-sizes-') as work:
        snapshot = Path(work) / DEFAULT_SCH.name
        snapshot.write_text(text)
        nets, pin_nets = export_netlist(snapshot, work)
    expected = endpoint_map(schematic, pin_nets)
    assigned, rows, plans = {}, [], []
    for symbol in schematic.symbols:
        sid, ref = one(symbol, 'uuid')[1], prop(symbol, 'Reference')
        value = prop(symbol, FIELD)
        if value:
            payload = json.loads(value)
            if payload.get('schema') != 1 or payload.get('owner_uuid') != sid:
                raise ValueError(f'{ref}: invalid or copied Wire.Sizes owner/schema')
            for entry in payload.get('entries', []):
                pin, scope = entry['pin'], entry['scope']
                key = sid, pin
                if key not in expected:
                    raise ValueError(f'{ref}.{pin}: missing, disconnected or replaced endpoint')
                if key in assigned:
                    raise ValueError(f'{ref}.{pin}: duplicate size declaration')
                if entry['net'] != expected[key][1]:
                    raise ValueError(f'{ref}.{pin}: declared net differs from native netlist')
                if scope not in SCOPES:
                    raise ValueError(f'{ref}.{pin}: unknown sizing scope {scope}')
                awg = entry.get('awg')
                if scope in FIXED:
                    if awg is not None:
                        raise ValueError(f'{ref}.{pin}: fixed/interface connection has an invented gauge')
                elif not isinstance(awg, int) or not 1 <= awg <= 40:
                    raise ValueError(f'{ref}.{pin}: expected an integer AWG from 1 to 40')
                assigned[key] = entry
                rows.append(dict(entry, reference=ref, symbol_uuid=sid))
        value = prop(symbol, PLAN_FIELD)
        if value:
            payload = json.loads(value)
            if payload.get('schema') != 1 or payload.get('owner_uuid') != sid:
                raise ValueError(f'{ref}: invalid or copied Wire.SizePlan owner/schema')
            for entry in payload.get('entries', []):
                if not isinstance(entry.get('awg'), int) or not 1 <= entry['awg'] <= 40:
                    raise ValueError(f'{ref}: invalid planned conductor AWG')
                if 'pin' in entry:
                    raise ValueError(f'{ref}: a mechanical size plan must not invent a symbol pin')
                plans.append(dict(entry, reference=ref, symbol_uuid=sid))
    missing = [f'{ref}.{pin}' for (sid, pin), (ref, net) in expected.items()
               if (sid, pin) not in assigned]
    return {
        'schema': 1, 'source_sha256': digest(text.encode()),
        'connected_pins': len(expected), 'sized_pins': len(rows),
        'complete_connection_sizing': not missing, 'missing': sorted(missing),
        'scopes': dict(Counter(r['scope'] for r in rows)),
        'entries': sorted(rows, key=lambda r: (r['reference'], r['pin'])),
        'planned_conductors': plans,
        'physical_wire_schedule_complete': False,
    }


def populate(text):
    """Apply the owner's approved sizes to this exact saved circuit inventory."""
    schematic = Schematic(text)
    with tempfile.TemporaryDirectory(prefix='powermatic-sizing-plan-') as work:
        snapshot = Path(work) / DEFAULT_SCH.name
        snapshot.write_text(text)
        _, pin_nets = export_netlist(snapshot, work)
    external = {
        'S2': {'5T', '6T', '2B', '1B', '3B'},
        'S3': {'1B', '1T', '2T'},
    }
    direct = {
        ('K4', '2'), ('K4', '4'), ('K4', '6'),
        ('K6', '2'), ('K6', '4'), ('K6', '6'),
        ('OL4', 'IN1'), ('OL4', 'IN2'), ('OL4', 'IN3'),
        ('OL6', 'IN1'), ('OL6', 'IN2'), ('OL6', 'IN3'),
    }
    # These are device identities, not guesses based on net-name patterns.
    power_values = {'RM25030-3SR', '222102', 'FAZ-D4/2-NA-L'}
    updates, chosen_external = {}, {'S2': set(), 'S3': set()}
    by_owner = {}
    for (sid, pin), (ref, net) in sorted(endpoint_map(schematic, pin_nets).items()):
        symbol = schematic.by_uuid[sid]
        value = prop(symbol, 'Value')
        scope, awg, note = None, None, ''
        if ref == 'J2':
            scope, awg = 'incoming_cable', 12
            note = 'Selected 12/4 incoming cable; panel-tail routing remains pending.'
        elif ref == 'M1':
            if pin == 'PE' and net == 'PE':
                scope, awg = 'motor_conduit', 12
                note = 'Motor-conduit PE to the bonding junction; attachment hardware remains installation work.'
            elif pin in {f'T{i}' for i in range(1, 7)}:
                scope, awg = 'motor_conduit', 14
                note = 'One external 14 AWG conductor per motor lead; factory motor lead size is separate.'
            else:
                raise ValueError('Motor pin inventory changed; review its conductor plan.')
        elif ref in external:
            if pin in external[ref]:
                scope, awg = 'controls_conduit', 16
                chosen_external[ref].add(pin)
                note = 'Individual external control wire; panel-side extensions use 18 AWG.'
            else:
                scope = 'retained_link'
                note = 'Retained switch jumper/strap; preserve the existing assembly.'
                if ref == 'S2':
                    note = ('Required station jumper 2B-4B; physical installation unconfirmed.'
                            if pin == '4B' else
                            'Installed station jumpers 1T-3T and 3T-5T; no external conductor.')
        elif ref == 'J1':
            scope, awg = 'factory_pigtail', 22
            note = 'T4171310004-001 factory 0.34 mm² / 22 AWG lead; any extension is a separate wire.'
        elif ref == 'J6':
            scope = 'connector_interface'
            note = 'M12 mating interface; retain the supplied assembly.'
        elif ref == 'S1':
            scope = 'estop_assembly'
            note = 'Retained E-stop assembly; supplied wiring stays as-is.'
        elif value == 'HMX1-SSVRC-DC':
            scope = 'suppressor_lead'
            note = 'Device-supplied suppressor connection; do not create a loose-wire purchase.'
        elif (ref, pin) in direct:
            scope = 'direct_mount'
            note = 'Direct-mounted overload power connection; no separate assembly wire.'
        elif value == 'NDR-240-24':
            if pin == '1_BOT':
                scope, awg = 'panel_pe', 14
            elif pin in {'2_BOT', '3_BOT'}:
                scope, awg = 'panel_power', 14
            else:
                scope, awg = 'panel_control', 18
                note = 'PSU duplicate output terminals are internally common; no jumper is implied.'
        elif value in power_values:
            scope, awg = 'panel_power', 14
        elif value == 'HTOR32-6-S' and pin in {'2', '4', '6'}:
            scope, awg = 'panel_power', 14
        elif value == 'HMC-9B30-11-DS' and pin in {'1', '2', '3', '4', '5', '6'}:
            scope, awg = 'panel_power', 14
            note = 'Gauge for discrete panel wire; reversing connection-kit bars retain their supplied form.'
        elif value in {'HMC-9B30-11-DS', 'HC3096N-52-900-24', 'HTOR32-6-S', 'XB4BVB1'}:
            scope, awg = 'panel_control', 18
            if pin.startswith(('A1.', 'A2.')):
                note = 'Duplicate coil terminals are internally common; this size does not imply a jumper.'
        else:
            raise ValueError(f'Unclassified connected component {ref} ({value}), pin {pin}.')
        entry = {'pin': pin, 'net': net, 'scope': scope, 'awg': awg}
        color = color_for(scope, pin)
        if color:
            entry['color'] = color
        if note:
            entry['note'] = note
        by_owner.setdefault(sid, []).append(entry)
    if chosen_external != external:
        raise ValueError('External control terminal inventory changed; review the 5+3 conductor plan.')
    for sid, entries in by_owner.items():
        updates[sid] = {FIELD: json.dumps({'schema': 1, 'owner_uuid': sid, 'entries': entries},
                                         ensure_ascii=False, separators=(',', ':'))}
    motor = schematic.endpoint('M1', 'T1')['symbol_uuid']
    motor_pe_plan = [] if (motor, 'PE') in endpoint_map(schematic, pin_nets) else [
        {'id': 'motor-conduit-pe', 'awg': 12, 'net': 'PE', 'scope': 'motor_conduit',
         'from': 'panel PE terminal', 'to': 'motor-end PE splice',
         'status': 'planned', 'note': 'Mechanical PE plan; M1 has no connected PE pin.'},
    ]
    updates[motor][PLAN_FIELD] = json.dumps({
        'schema': 1, 'owner_uuid': motor,
        'entries': motor_pe_plan + [
            {'id': 'motor-body-bond', 'awg': 10, 'net': 'PE', 'scope': 'prefab_bond',
             'from': 'motor-end PE splice', 'to': 'motor body', 'status': 'proposed',
             'note': 'GRDKIT01 supplied assembly if selected; attachment hardware remains open.'},
            {'id': 'machine-frame-bond', 'awg': 10, 'net': 'PE', 'scope': 'prefab_bond',
             'from': 'motor-end PE splice', 'to': 'machine frame', 'status': 'proposed',
             'note': 'GRDKIT01 supplied assembly if selected; attachment hardware remains open.'},
        ]}, separators=(',', ':'))
    psu = schematic.endpoint('PS1', '1_BOT')['symbol_uuid']
    updates[psu][PLAN_FIELD] = json.dumps({
        'schema': 1, 'owner_uuid': psu,
        'entries': [{'id': 'enclosure-door-bond', 'awg': 10, 'net': 'PE', 'scope': 'prefab_bond',
                     'from': 'enclosure stud', 'to': 'door stud', 'status': 'proposed',
                     'note': 'GRDKIT01 supplied assembly if selected; stud fit/length remain open.'}]},
        separators=(',', ':'))
    result = change_fields(text, updates)
    # Remove only these sizing fields from the candidate: the drawing, other
    # metadata and existing wire records must be byte-for-byte preserved.
    candidate = Schematic(result)
    if nodes(candidate.tree, 'wire') != nodes(schematic.tree, 'wire'):
        raise ValueError('Unexpected wire geometry change.')
    clean = lambda s: [p for p in s if not (isinstance(p, list) and
                        p[0] == 'property' and p[1] in {FIELD, PLAN_FIELD})]
    if [clean(s) for s in candidate.symbols] != [clean(s) for s in schematic.symbols]:
        raise ValueError('Unexpected existing symbol change.')
    return result


def markdown(report):
    lines = ['# Schematic connection sizing', '',
             'Sizes are custom Wire.Sizes symbol fields in the schematic. These declarations',
             'classify connected terminals; they do not choose physical terminal routes,',
             'create jumpers between internally common pins or define cut lengths.', '',
             f'Connected terminals classified: {report["sized_pins"]}/{report["connected_pins"]}.',
             f'Connection sizing complete: {report["complete_connection_sizing"]}.',
             'Physical conductor schedule and terminal allocation remain pending.', '',
             '| Terminal | Net | Scope | AWG | Color |', '|---|---|---|---|---|']
    for r in report['entries']:
        lines.append(f'| {r["reference"]}.{r["pin"]} | {r["net"]} | {r["scope"]} | '
                     f'{r["awg"] if r["awg"] is not None else "—"} | '
                     f'{r.get("color", "")} |')
    lines += ['', '## Planned PE conductors', '', '| Plan | AWG | Status |', '|---|---|---|']
    lines += [f'| {r["id"]} | {r["awg"]} | {r["status"]} |' for r in report['planned_conductors']]
    lines += ['', 'The existing Wire.Wxxx physical-wire records still require reconciliation',
              'with the PCB-only terminal model. Fixed lead sizes and conductor protection',
              'must be checked against the actual component and installation.', '']
    return '\n'.join(lines)


def main():
    parser = argparse.ArgumentParser(description=__doc__)
    parser.add_argument('--schematic', type=Path, default=DEFAULT_SCH)
    parser.add_argument('--stage', type=Path, help='write a candidate copy; never overwrites the source')
    parser.add_argument('--report', type=Path, help='write derived Markdown and JSON reports')
    args = parser.parse_args()
    try:
        text = args.schematic.read_text()
        if args.stage:
            if args.stage.resolve() == args.schematic.resolve():
                raise ValueError('Staging must not overwrite the source schematic.')
            result = populate(text)
        else:
            result = text
        report = inspect(result)
        if not report['complete_connection_sizing']:
            raise ValueError('Unclassified connected terminals: ' + ', '.join(report['missing']))
        if args.stage:
            args.stage.parent.mkdir(parents=True, exist_ok=True)
            args.stage.write_text(result)
        if args.report:
            args.report.parent.mkdir(parents=True, exist_ok=True)
            args.report.write_text(markdown(report))
            args.report.with_suffix('.json').write_text(json.dumps(report, indent=2) + '\n')
        print(f'Classified {report["sized_pins"]} connected terminals; '
              f'{report["scopes"]["controls_conduit"]} external control wires. '
              'Physical routes remain pending.')
    except (ValueError, KeyError, OSError) as error:
        parser.exit(2, f'Wire sizing failed: {error}\n')


if __name__ == '__main__':
    main()

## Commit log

2026-08-05 Initial Powermatic 1200 project files
2026-08-06 Finalize Rev J documentation layout
    Move Rev J documents into docs/ and keep helper generators in scripts/. Remove archived prior revisions, replace the Rev J BOM PDF, and align the control documentation with the latest jog, selector, SCCR, and indicator-lamp decisions.
2026-08-06 Promote Powermatic retrofit documentation to Rev K
2026-08-07 Promote Powermatic retrofit documentation to Rev M
2026-08-13 update Rev M BOM workbook
2026-09-23 preparing project for kicad
2026-09-25 Archive Rev P controls and panel layout assets
    Preserve the current BOM, saved KiCad project, terminal reviews, and sourced STEP models and drawings before workspace cleanup. Record the existing removal of obsolete Rev M files and ignore KiCad lo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
    [14070532.step, 148E1111.step, 22013003.step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]
2026-09-25 Keep active project focused on BOM and KiCad
    Remove mechanical assets and generated reports after preserving them in archive commit 8ceac95 and verifying shared _parts copies. Replace superseded project notes with current scope and remaining work.
    [14070532.step, 148E1111.step, 22013003.step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]
2026-09-25 Updated controls parts
    [14070532.dxf, 148E1111.dxf, 22013003.dxf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]
2026-09-26 PCB footprint and model work
    [Powermatic_BOM_revP.csv, powermatic_1200.kicad_pcb, powermatic_1200.kicad_sch]
2026-09-29 Advance motor-control wiring and use shared Controls assets
    Save the current power, stop-chain, direction-holding, and speed-coil wiring checkpoint. Simplify contactor references, use the BACO disconnect, and migrate project-local Controls assets to _parts wi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
    [powermatic_1200.kicad_pcb, powermatic_1200.kicad_sch]
2026-09-30 added duct and din
    [powermatic_1200.kicad_pcb, powermatic_1200.kicad_sch]
2026-10-01 panel layout
    [powermatic_1200.kicad_pcb, powermatic_1200.kicad_sch]
2026-10-02 selected larger enclosure
    [powermatic_1200.kicad_pcb]
2026-10-02 Update enclosure BOM, footprint artwork, and assembly model alignment
    Preserve detailed drawings on F.Fab, use simplified F.SilkS outlines and F.Adhes fills, and align contactor accessories to the nominal Fusion assembly. Include current schematic and terminal placement edits, model verification tools, and review artifacts.
    Record reconciliation with the shared parts rail export. KiCad loads all 58 board footprints, model checks pass, and the schematic netlist exports successfully. Nominal assembly alignment is not a collision-free fit approval.
    [Powermatic_BOM_revP.csv, powermatic_1200.kicad_pcb, powermatic_1200.kicad_sch]
2026-10-03 finalized panel layout
    [14070532.dxf, 148E1111.dxf, 22013003.dxf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]
2026-10-06 terminal block wiring
    [Powermatic_BOM_revP.csv, Wire_schedule.csv, Wire_schedule_generated.csv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]
2026-10-06 massage schematic for understanding
    [powermatic_1200.kicad_pcb, powermatic_1200.kicad_sch]
2026-10-08 Integrate vintage controls and standardize panel artwork
    Update the schematic, PCB, BOM and wiring-size/termination tools for the control-station and conduit plans. Preserve physical terminal mappings and detailed Fab artwork while reserving user layers for enclosure information. Include KiCad migration and review checkpoints; native DRC remains unverified after checker crashes.
    [Powermatic_BOM_revP.csv, Q1.kicad_pcb, S2.kicad_pcb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]
2026-10-08 Establish baseline after historical cleanup
    Remove archived drawings, historical review snapshots, retired tooling and wiring-estimate artifacts. Retain the current BOM, wiring policy and KiCad design as the active baseline.
    [14070532.dxf, 148E1111.dxf, 22013003.dxf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]
2026-10-09 Update panel wiring metadata and KiCad schedule extraction
    [Powermatic_BOM_revP.csv, Wire_schedule.csv, powermatic_1200.kicad_pcb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]
2026-10-09 Configure DIN routing grids and update fuse-holder layout
    [pin_coordinates.xlsx, powermatic_1200.kicad_pcb, powermatic_1200.kicad_sch]
2026-10-10 Update panel layout, busbar assemblies, and wire schedules
    [Powermatic_BOM_revP.csv, Wire_schedule.csv, powermatic_1200.kicad_pcb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]
2026-10-19 Document BOM quantity audit and reviewer behavior
2026-10-19 Correct wire requirements and motor splice purchasing
2026-10-19 Select 221-612 motor splices and matching strip lengths
2026-10-19 Update saved control schematic and panel layout
2026-10-19 Remove retired source metadata from BOM
2026-10-19 Retain outstanding receipt flags in the project BOM
2026-10-21 Bond all DIN rails and refresh wire schedule
2026-10-21 Add TB50 enclosure bond and 5/16-inch ring terminal
2026-10-21 Use supplied door bond and separate J-box grounding branches
2026-10-28 Document backplate installation and DIN rail layout
    Record the completed 20-hole 10-24 installation, add the component layout diagram, and describe wiring schedule generation through the external bom_review adapter.
2026-10-28 Publish BOM review state and double-D punch package
    Save the cleared receipt flags, the existing Rev A prototype tooling package and references, and the separate backpanel layout sheet. Purchasing quantities and prices are unchanged.
2026-10-29 Update enclosure entries, terminal layout, and installation guides
    Record right-face entry holes and relocate incoming power terminals while retaining their labels. Refresh wire lengths, BOM requirements, DIN layout, jumper guides, and saved schematic changes.
    Specify two McMaster 9357K15 gasketed plugs for the unused motor/control entry pair and publish the Rev I portrait tabloid enclosure drawing.
2026-11-09 Save current wiring design and consolidate essential documentation
2026-11-09 Remove generated footprint cache and ignore future copies
